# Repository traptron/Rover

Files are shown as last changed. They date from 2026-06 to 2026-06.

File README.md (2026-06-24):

# Rover - Инструкция по аппаратному обеспечению и тестированию

Данный документ содержит полное описание архитектуры прошивки, распиновку для подключения аппаратной части (драйверов DRV8871 и энкодеров) к микроконтроллеру STM32F429ZI, а также инструкцию по диагностике и тестированию системы.

---

## 1. Аппаратное подключение к STM32 
В помощь https://os.mbed.com/platforms/ST-Nucleo-F429ZI/

### 1.1. Драйверы двигателей DRV8871
Каждый из 6 моторов управляется отдельным драйвером DRV8871. Управление осуществляется по двум линиям: `IN1` (ШИМ-сигнал мощности) и `IN2` (логический уровень направления).

**Особенности работы с DRV8871:**
В прошивке реализована специальная логика для исключения состояния аппаратного торможения (Brake), когда на обоих входах драйвера логическая `1`:
- **Движение вперед:** `IN2` (DIR) = 0, `IN1` (PWM) = Прямая скважность от ПИД-регулятора.
- **Движение назад:** `IN2` (DIR) = 1, `IN1` (PWM) = Инвертированная скважность (`MAX_PWM - |мощность|`).

| Мотор | Сторона | Пин IN2 (DIR) | Пин IN1 (PWM) | Таймер и Канал ШИМ |
|---|---|---|---|---|
| **0** | Левая | **PF0** | **PE5** | TIM9_CH1 |
| **1** | Левая | **PF1** | **PF6** | TIM10_CH1 |
| **2** | Левая | **PF2** | **PF7** | TIM11_CH1 |
| **3** | Правая  | **PF3** | **PB15** | TIM12_CH2 |
| **4** | Правая  | **PF4** | **PF8** | TIM13_CH1 |
| **5** | Правая  | **PF5** | **PF9** | TIM14_CH1 |

*💡 Примечание:* Если при команде "вперед" какой-то мотор крутится назад, вы можете либо физически поменять местами силовые провода мотора (рекомендуется), либо программно инвертировать логику для конкретного мотора в `Core/Src/motor.c`.

### 1.2. Аппаратные энкодеры
Для определения текущей скорости и пробега используются квадратурные энкодеры. Выходы фаз A и B подключены напрямую к входам аппаратных таймеров STM32, работающих в режиме аппаратного энкодера.

| Энкодер | Пин Фазы A (CH1) | Пин Фазы B (CH2) | Используемый Таймер |
|---|---|---|---|
| **0** | **PE9** | **PE11** | TIM1 |
| **1** | **PA5** | **PB3** | TIM2 (32-bit) |
| **2** | **PA6** | **PB5** | TIM3 |
| **3** | **PD12** | **PD13** | TIM4 |
| **4** | **PA0** | **PA1** | TIM5 (32-bit) |
| **5** | **PC6** | **PC7** | TIM8 |

### 1.3. Связь с управляющим компьютером (UART4)
Обмен телеметрией и целевыми командами (Target Speeds) с хостом (например, Orange Pi или Raspberry Pi) происходит по интерфейсу UART с использованием DMA для минимизации нагрузки на процессор. Скорость обмена — **115200 бод**, частота отправки пакетов — 50 Гц (20 мс).

- **PC10 (TX)** -> RX-пин Orange Pi.
- **PC11 (RX)** -> TX-пин Orange Pi.
- **GND** -> **ОБЯЗАТЕЛЬНО** соедините земли (GND) STM32 и Orange Pi вместе.

В системе реализован **Failsafe**: если валидные пакеты от управляющего ПК не приходят более 500 мс, все моторы принудительно останавливаются, чтобы избежать аварии.

---

## 2. Сборка и Прошивка 

Обновление программного обеспечения микроконтроллера требует перекомпиляции и загрузки новой прошивки:

1. **Сборка проекта:** Скомпилируйте проект в вашей IDE (или через терминал `cmake --build build`). Дождитесь сообщения об успешном завершении сборки.
2. **Прошивка STM32:** Загрузите полученный файл `Rover.elf` / `Rover.bin` через ST-Link с помощью STM32CubeProgrammer или встроенных средств вашей IDE.
3. **Перезагрузка:** Нажмите кнопку **Reset** на микроконтроллере для запуска нового кода.

*(Если не прошить контроллер, плата продолжит выполнять старый код).*

---

## 3. Управляющий ПК: Зависимости и Установка

Для запуска скрипта тестирования `test_serial.py` и работы ROS 2 пакета `uart_bridge_pkg` на управляющем компьютере (например, Orange Pi 3b) необходимо установить следующие зависимости.

### 3.1. Список зависимостей
* **Системные (ROS 2 Humble):** `rclpy`, `geometry_msgs`, `nav_msgs`, `std_msgs` (поставляются вместе со средой ROS 2).
* **Python-библиотеки:**
  * `pyserial` — обмен данными с STM32 через UART.
  * `Flask` — веб-сервер панели мониторинга.
  * `Flask-SocketIO` — WebSocket-сервер для обновления графиков в реальном времени.

### 3.2. Команды для установки

**Способ 1: Через пакетный менеджер APT (Рекомендуется для Orange Pi / Ubuntu)**
Устанавливает зависимости на системном уровне без конфликтов с PEP 668:
```bash
sudo apt update
sudo apt install python3-serial python3-flask python3-flask-socketio
```

**Способ 2: Через pip**
Если вы используете виртуальное окружение или устанавливаете библиотеки напрямую:
```bash
pip3 install pyserial Flask Flask-SocketIO
```
*Примечание: на современных версиях ОС при попытке глобальной установки pip выдаст ошибку "externally-managed-environment". В этом случае используйте флаг `--break-system-packages`:*
```bash
pip3 install pyserial Flask Flask-SocketIO --break-system-packages
```

### 3.3. Настройка прав доступа к UART-порту
Для доступа к последовательным интерфейсам без прав `sudo` добавьте пользователя в группу `dialout`:
```bash
sudo usermod -a -G dialout $USER
```
*После выполнения команды перезайдите в систему или перезапустите ПК.*

---

## 4. Тестирование и диагностика (test_serial.py)

Для базовой проверки электроники без необходимости разворачивать ROS2 стек, используйте утилиту `Scripts/test_serial.py`.

### 4.1. Запуск
Подключите управляющий компьютер к STM32 по UART и выполните команду:
```bash
python3 Scripts/test_serial.py
```
*(Убедитесь, что переменная `SERIAL_PORT` в скрипте указывает на правильный порт, например `/dev/ttyS7` или `/dev/ttyUSB0`).*

### 4.2. Порядок проверки системы

**Шаг 1. Проверка чтения энкодеров (без моторов)**
1. Запустите скрипт, не подавая команду на скорость (`linear_x = 0`).
2. Вручную вращайте колеса ровера вперед по одному.
3. В консоли должны обновляться данные энкодеров: `[RX] Энкодеры: (15, 0, 0, 0, 0, 0)`.
4. При вращении вперед значения должны **расти** (в плюс), при вращении назад — **уменьшаться** (в минус).
5. *🔧 Исправление:* Если при вращении вперед значение уходит в минус, **поменяйте местами провода фаз A и B** на колодке контроллера для данного мотора.

**Шаг 2. Проверка моторов и ПИД-регулятора**
1. Введите в терминал скрипта тестовую скорость: `linear_x: 0.3` (Enter).
2. Моторы начнут вращаться. ПИД-регулятор внутри STM32 автоматически подберет необходимую мощность ШИМ на основании обратной связи от энкодеров.
3. Попробуйте придержать вращающееся колесо рукой — вы почувствуете увеличение крутящего момента (работа интегральной компоненты ПИД).
4. Введите `linear_x: 0.0` для остановки моторов.

---

## 5. Частые проблемы и их решение

* **Энкодеры всегда показывают нули:** 
  Убедитесь в наличии питания (3.3V/5V) на энкодерах. Проверьте правильность подключения сигнальных пинов к `TIMx_CH1` и `TIMx_CH2`.

* **Мотор уходит "вразнос" (мгновенно раскручивается до 100% при малой заданной скорости):**
  Возникла положительная обратная связь ПИД-регулятора. Мотор физически крутится вперед, но энкодер инвертирован и считает в минус. ПИД пытается "догнать" целевую скорость, увеличивая мощность ШИМ до максимума.
  **Решение:** Поменяйте местами фазы A и B энкодера ИЛИ поменяйте местами силовые провода мотора (в зависимости от того, куда физически едет колесо).

* **Ошибка CRC (`Ошибка CRC: calc=XX, recv=YY`) в скрипте:**
  Нарушена целостность данных по UART. Убедитесь в надежности контактов, наличии общего GND и, при необходимости, используйте экранированные провода или снизьте скорость (Baud Rate).

* **Пакеты идут без ошибок CRC, но моторы стоят:**
  Проверьте силовое питание (12V/24V) на драйверах DRV8871. Убедитесь, что силовая земля (GND) батареи объединена с сигнальной GND STM32. С помощью осциллографа или мультиметра проверьте уровни на пинах `IN2` (DIR, PF0-PF5) и наличие генерации на пинах `IN1` (PWM).

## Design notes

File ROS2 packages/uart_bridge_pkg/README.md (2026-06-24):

# Uart Bridge Package (`uart_bridge_pkg`)

ROS 2 пакет для мостового соединения (UART Bridge) между одноплатным компьютером Orange Pi 3b и микроконтроллером STM32. 

Нода `uart_bridge_node` транслирует команды управления движением (`/cmd_vel`) в бинарные пакеты для STM32, а также читает данные 6 энкодеров по UART, рассчитывает одометрию с помощью прямой кинематики (skid-steering) и публикует ее в топик `/odom`. Кроме того, нода поддерживает динамическое изменение параметров ПИД-регуляторов моторов "на лету" (например, через `rqt`).

## Особенности
* **Прямая трансляция управления:** Конвертирует `geometry_msgs/msg/Twist` в компактные бинарные UART-пакеты с расчетом контрольной суммы (CRC-8).
* **Расчет одометрии (Skid-Steering):** Опрашивает энкодеры в отдельном потоке, переводит тики в метры и вычисляет координаты X, Y, Theta на основе ширины колеи (290 мм) и геометрии 6 колес.
* **Настройка ПИД "на лету":** Обработчик параметров ROS 2 позволяет отправлять пакеты настройки на микроконтроллер без перезапуска ноды.
* **Веб-дашборд (`web_dashboard_node`):** Встроенный Flask + SocketIO сервер для отображения графиков энкодеров в реальном времени и настройки ПИД-коэффициентов через веб-интерфейс в локальной сети.

## Топики

### Подписки (Subscribers)
* **`/cmd_vel`** (`geometry_msgs/msg/Twist`): Целевая скорость робота. 
  * Используются поля `linear.x` (линейная скорость) и `angular.z` (угловая скорость).

### Публикации (Publishers)
* **`/odom`** (`nav_msgs/msg/Odometry`): Локальная одометрия робота (X, Y, Theta). 
  * Публикуется с фреймами `odom` -> `base_link` (публикация TF-трансформации отключена).
* **`/encoders_raw`** (`std_msgs/msg/Int32MultiArray`): Сырые значения энкодеров (разница тиков с прошлого пакета) для всех 6 колес. Используется для отладки.

## Параметры ROS 2 (Parameters)

| Имя параметра | Тип | По умолчанию | Описание |
|---|---|---|---|
| `serial_port` | string | `/dev/ttyS7` | Имя устройства UART-порта на Orange Pi 3b |
| `baudrate` | integer | `115200` | Скорость передачи данных UART |
| `motor_id` | integer | `0` | ID мотора (0-5) для отправки новых ПИД-коэффициентов |
| `kp` | double | `1.0` | Пропорциональный коэффициент (P) для `motor_id` |
| `ki` | double | `0.0` | Интегральный коэффициент (I) для `motor_id` |
| `kd` | double | `0.0` | Дифференциальный коэффициент (D) для `motor_id` |

*Примечание: При изменении параметров `kp`, `ki`, `kd` или `motor_id` (например, через `rqt` или `ros2 param set`), нода автоматически формирует пакет и отправляет его по UART в STM32.*

## Зависимости

Для работы пакета требуются следующие зависимости:

### Системные зависимости (ROS 2 Humble)
Обычно поставляются вместе с базовой установкой ROS 2:
* `rclpy`
* `geometry_msgs`
* `nav_msgs`
* `std_msgs`

### Python-зависимости
Для связи по UART и работы веб-интерфейса панели управления:
* `pyserial` — для работы с последовательным портом UART.
* `Flask` — веб-фреймворк для бэкенда панели.
* `Flask-SocketIO` — WebSocket-сервер для передачи показаний в реальном времени.

### Команды для установки зависимостей

**Вариант 1: Установка через пакетный менеджер APT (Рекомендуется на Orange Pi / Ubuntu)**
Этот способ предпочтителен, так как он устанавливает пакеты системно и не вызывает конфликтов с PEP 668:
```bash
sudo apt update
sudo apt install python3-serial python3-flask python3-flask-socketio
```

**Вариант 2: Установка через pip**
Если вы используете виртуальное окружение или системные пакеты недоступны:
```bash
pip3 install pyserial Flask Flask-SocketIO
```
*Примечание: на современных ОС (например, Debian 12 / Ubuntu 24.04 / Armbian) при попытке глобальной установки pip выдаст ошибку "externally-managed-environment". В таком случае можно использовать флаг `--break-system-packages`:*
```bash
pip3 install pyserial Flask Flask-SocketIO --break-system-packages
```

---

## Установка и сборка

1. Перенесите папку `uart_bridge_pkg` в директорию `src` вашего ROS 2 workspace на Orange Pi 3b.
   ```bash
   cd ~/ros2_ws/src
   # Убедитесь, что папка uart_bridge_pkg находится здесь
   ```

2. Соберите пакет с помощью `colcon`:
   ```bash
   cd ~/ros2_ws
   colcon build --packages-select uart_bridge_pkg
   ```

3. Подгрузите окружение workspace:
   ```bash
   source install/setup.bash
   ```

## Запуск

### Базовый запуск
Теперь вы можете запустить обе ноды (UART мост и веб-дашборд) одной командой:
```bash
ros2 launch uart_bridge_pkg rover_bridge.launch.py
```

### Запуск отдельных компонентов
Если вам нужно запустить только UART мост:
```bash
ros2 run uart_bridge_pkg uart_bridge_node --ros-args -p serial_port:=/dev/ttyS0 -p baudrate:=115200
```
Для запуска только веб-дашборда:
```bash
ros2 run uart_bridge_pkg web_dashboard_node
```

После запуска интерфейса (через `launch` или отдельно), откройте браузер на любом устройстве в вашей локальной сети по адресу:
`http://<IP_адрес_Orange_Pi>:5000`

## Права доступа к UART
Убедитесь, что ваш пользователь на Orange Pi находится в группе `dialout` (или `tty`), чтобы иметь права на чтение/запись в `/dev/ttyS7` без `sudo`:
```bash
sudo usermod -a -G dialout $USER
# После этого нужно перезайти в систему или выполнить su - $USER
```

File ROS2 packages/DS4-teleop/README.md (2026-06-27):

# Телеоперация 6-колёсного ровера через DualShock 4

Узел ROS2 Humble для управления 6-колёсным ровером с помощью джойстика DualShock 4, подключённого по Bluetooth к Orange Pi 3B.

## Архитектура

```
DualShock 4 (Bluetooth)
    ↓
/dev/input/event5
    ↓
joy_node → /joy (sensor_msgs/Joy)
    ↓
teleop_node → /cmd_vel (geometry_msgs/Twist)
    ↓
STM32 Motor Controller (UART)
```

## Управление

| Действие | Кнопка | Эффект |
|---|---|---|
| Движение вперёд | R2 (триггер) | linear.x → [0, +max] |
| Движение назад | L2 (триггер) | linear.x → [-max, 0] |
| Поворот | Left Stick X | angular.z → [-max, +max] |

**Нормализация триггеров:** Триггеры из диапазона `[1.0, -1.0]` переводятся в `[0, 1]` по формуле:
```
value = (1.0 - axis) / 2.0
```

## Быстрый старт

### 1. Сборка пакета

```bash
cd ~/rover_ws
colcon build --packages-select teleop_DS4
source install/setup.bash
```

### 2. Запуск системы

```bash
ros2 launch teleop_DS4 teleop.launch.py joy_device:=/dev/input/event5
```

### 3. Отладка (с выводом логов)

```bash
ros2 launch teleop_DS4 teleop.launch.py \
  joy_device:=/dev/input/event5 \
  debug:=true
```

## Мониторинг

### Просмотр команд скорости

```bash
ros2 topic echo /cmd_vel
```

### Просмотр входных данных джойстика

```bash
ros2 topic echo /joy
```

### Список параметров

```bash
ros2 param list /teleop_ds4_node
```

## Параметры

| Параметр | Тип | Значение по умолчанию | Описание |
|---|-----|---|---|
| `max_linear_speed` | float | 1.0 | Максимальная линейная скорость (м/с) |
| `max_angular_speed` | float | 1.0 | Максимальная угловая скорость (рад/с) |
| `deadzone` | float | 0.05 | Мёртвая зона для аналоговых входов [0, 1] |
| `accel_limit` | float | 0.5 | Ограничение ускорения (ед/с²) |
| `watchdog_timeout` | float | 0.2 | Таймаут отказа безопасности (сек) |
| `debug` | bool | false | Включить отладочные логи |

### Изменение параметров во время работы

```bash
# Установить максимальную скорость
ros2 param set /teleop_ds4_node max_linear_speed 2.0

# Включить отладку
ros2 param set /teleop_ds4_node debug true
```

## Безопасность

1. **Watchdog Timer** — если сообщение от джойстика не получено в течение 200 мс, публикуется нулевая скорость
2. **Deadzone** — входы ниже порога 0.05 игнорируются (исключает дрейф)
3. **Rate Limiting** — ограничение ускорения предотвращает резкие прыжки скорости
4. **Clamping** — все выходы ограничены диапазоном `[-max, +max]`

## Техническое описание

### Вычисление скорости

```python
# Нормализация триггеров
L2_norm = (1.0 - L2_raw) / 2.0   # [1, -1] → [0, 1]
R2_norm = (1.0 - R2_raw) / 2.0   # [1, -1] → [0, 1]

# Вычисление желаемых скоростей
linear = (R2_norm - L2_norm) * max_linear_speed
angular = left_stick_x * max_angular_speed

# Применение мёртвой зоны, ограничение и сглаживание
# ...

# Публикация
twist.linear.x = linear
twist.angular.z = angular
```

### Цикл управления

- **Основной цикл** — 50 Гц (публикация `/cmd_vel`)
- **Watchdog** — 100 Гц (проверка timeout)
- **Отладочные логи** — 5 Гц (throttled)

## Устранение неполадок

### Джойстик не распознаётся

```bash
# Проверить, что устройство доступно
ls -la /dev/input/event*

# Проверить права доступа
sudo usermod -a -G input $USER
```

### Нет команд на `/cmd_vel`

```bash
# Проверить, что joy_node работает
ros2 topic echo /joy

# Если нет данных, проверить джойстик
ros2 node list | grep joy
```

### Предупреждения Watchdog

```
[WARN] Watchdog timeout: no joy message for 0.200s
```
Джойстик потерял связь. Проверьте Bluetooth соединение.

## Индексы осей DualShock 4 (стандартная нумерация)

| Ось | Индекс | Диапазон | Описание |
|-----|---|---|---|
| LX | 0 | [-1, 1] | Left stick X |
| LY | 1 | [-1, 1] | Left stick Y |
| RX | 2 | [-1, 1] | Right stick X |
| RY | 3 | [-1, 1] | Right stick Y |
| L2 | 4 | [1, -1] | L2 триггер |
| R2 | 5 | [1, -1] | R2 триггер |

## Зависимости

- ROS2 Humble
- rclpy
- sensor_msgs
- geometry_msgs
- joy (пакет для чтения джойстика)

## Сборка и установка

```bash
# Вспомогательные зависимости
rosdep install --from-paths src --ignore-src -r -y

# Сборка
colcon build --packages-select teleop_DS4

# Источник
source install/setup.bash
```

## Тестирование

```bash
# Запустить с тестовыми параметрами
ros2 launch teleop_DS4 teleop.launch.py \
  max_linear_speed:=0.5 \
  max_angular_speed:=0.5 \
  debug:=true
```

## Лицензия

Apache-2.0

## Автор

traptron

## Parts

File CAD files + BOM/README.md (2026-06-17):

# BOM для rocker-bogie ровера

Этот список содержит CAD детали и электронику/механику для проекта rocker-bogie ровера. Количества указаны на один ровер.

## CAD детали (3D печать или мехобработка)

- Колесо, обод, шина, крепление: 6 шт
- Rocker, bogie: 2 шт
- Корпус: по 1 шт на каждую деталь
- Дифференциальная балка: 1 шт

## Электроника и механика

- Плата питания: 1 шт (описание ниже)

| Наименование | Кол-во | Ссылка |
| --- | --- | --- |
| Orange Pi 3B (рекомендуется 8GB RAM) | 1 | - |
| NUCLEO STM32F429ZI | 1 | - |
| JGA25-370 12V 130rpm с энкодером | 6 | https://aliexpress.ru/item/32855724293.html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 |
| XL4015 DC-DC step-down | 1-2 | - |
| Аккумулятор 18650 | 8 | - |
| Держатель 18650 на 4 слота | 2 | https://aliexpress.ru/item/1005003595795784.html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 |
| BMS 4S 16.8V 40A (рекомендуется 100A) | 1 | https://aliexpress.ru/item/4000274128382.html?spm=a2g2w.orderlist.0.0.48514aa6wYXTMo&sku_id=12000037978159621 |
| Зарядное устройство 16.8V 2A | 1 | https://aliexpress.ru/item/1005006648286527.html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 |
| DRV8871 H-bridge | 6 | https://aliexpress.ru/item/1005009205001091.html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 |
| Переключатель KCD4 | 1 | https://aliexpress.ru/item/10000335722912.html?spm=a2g2w.orderlist.0.0.48514aa6wYXTMo&sku_id=20000000175766813 |
| Шарнирные наконечники SI8 | 2 | https://aliexpress.ru/item/1005005898128558.html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 |
| Шарнирные наконечники SA8 | 2 | https://aliexpress.ru/item/1005005898128558.html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 |
| Подшипник 608zz | 10 | https://aliexpress.ru/item/1005006648286527.html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 |
| DC-099 разъем питания 5.5x2.1 | 1 | https://aliexpress.ru/item/1005008928703998.html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 |

## Плата питания

Плата изготавливается методом ЛУТ (https://youtu.be/NJTeIALlztI?si=GeW6YX7Ok-37P5MD). Для своей платы я использовал тонкий (0.5 мм) стеклотекстолит с двухсторонним фольгированием, лучше брать текстолит потолще с слоем меди 70 мкм. Если слой меди около 30 мкм и менее, рекомендуется усилить дорожки медным проводом. Плата травилась в водном растворе персульфата аммония при температуре 40-50 градусов, при температуре меньше 40 градусов реакция практически не идёт. На плате предусмотрены площадки под разъёмы XT30 для подключаемой нагрузки (драйверы, преобразователи напряжения и т.д.). Для подключения разъёмов следует припаять провода от дорожек VCC и GND (обратная сторона платы) соответсвенно к + и - выходов XT30.

## Критерии подбора компонентов

- BMS: непрерывный ток должен быть выше суммарного пикового тока всех моторов с запасом.
- Драйверы моторов: поддержка напряжения 12V и достаточный ток на канал с учетом пусковых токов.
- Энкодеры: желательно 2-канальные (квадратурные) для контроля направления и скорости.
- Аккумуляторы: одинаковая емкость и внутренняя сопротивляемость для ровной работы 4S сборки.
- DC-DC: обеспечить запас по мощности для одновременной нагрузки контроллеров и логики.

## Заметки по проводке

- Силовая проводка: AWG10 или AWG12.
- Балансные линии BMS: тонкие провода малого сечения.
- Логика: DuPont провода.

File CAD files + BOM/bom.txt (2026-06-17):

Wheel, Rim, Tire, Mount - 6 pieces
Rockie, Bogie - 2 pieces
Body - 1 piece for each part
Differential bar - 1 piece

Orange Pi 3B (8GB RAM recommended) - 1 piece
NUCLEO STM32F429ZI - 1 piece
JGA25-370 12V 130rpm with encoder - 6 pieces https://aliexpress.ru/item/32855724293.html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
XL4015 DC-DC step-down - 1-2 pieces 
18650 Battery - 8 pieces
18650 Battery holder 4x slot - 2 pieces https://aliexpress.ru/item/1005003595795784.html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
BMS 4S 16.8V 40A (100A recommended) - 1 piece https://aliexpress.ru/item/4000274128382.html?spm=a2g2w.orderlist.0.0.48514aa6wYXTMo&sku_id=12000037978159621
Charger 16.8V 2A - 1 piece https://aliexpress.ru/item/1005006648286527.html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
DRV8871 H-bridge - 6 pieces https://aliexpress.ru/item/1005009205001091.html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
KCD4 rocker switch - 1 piece https://aliexpress.ru/item/10000335722912.html?spm=a2g2w.orderlist.0.0.48514aa6wYXTMo&sku_id=20000000175766813
Rod Ends SI8 - 2 pieces https://aliexpress.ru/item/1005005898128558.html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
Rod Ends SA8 - 2 pieces https://aliexpress.ru/item/1005005898128558.html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
Bearing 608zz - 10 pieces https://aliexpress.ru/item/1005006648286527.html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
DC-099 Power Jack Socket 5.5x2.1 - 1 piece https://aliexpress.ru/item/1005008928703998.html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

For power wiring, AWG10 or AWG12 wires are required.
For BMS use small cross-section wires.
For logic use DuPont wires.

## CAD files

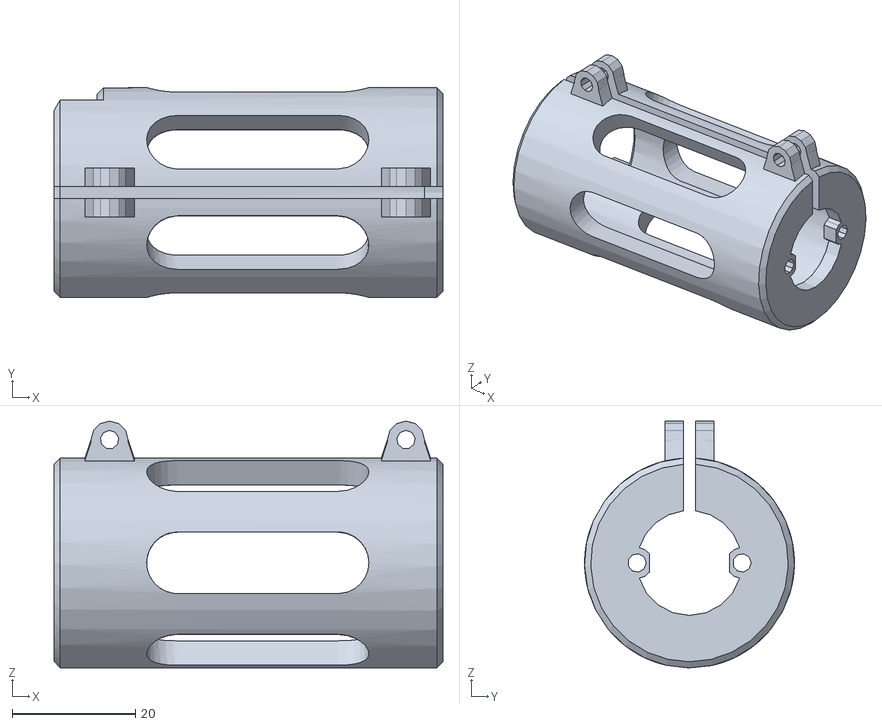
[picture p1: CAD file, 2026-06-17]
CAD files + BOM/Motor mount.stl
63.0 x 34.0 x 40.0

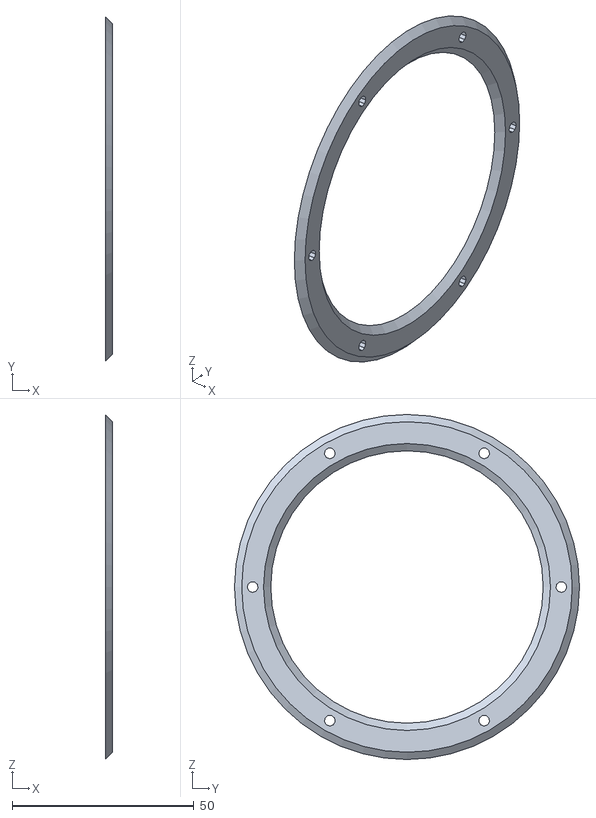
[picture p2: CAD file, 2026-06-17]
CAD files + BOM/Rim.stl
2.00 x 95.0 x 95.0

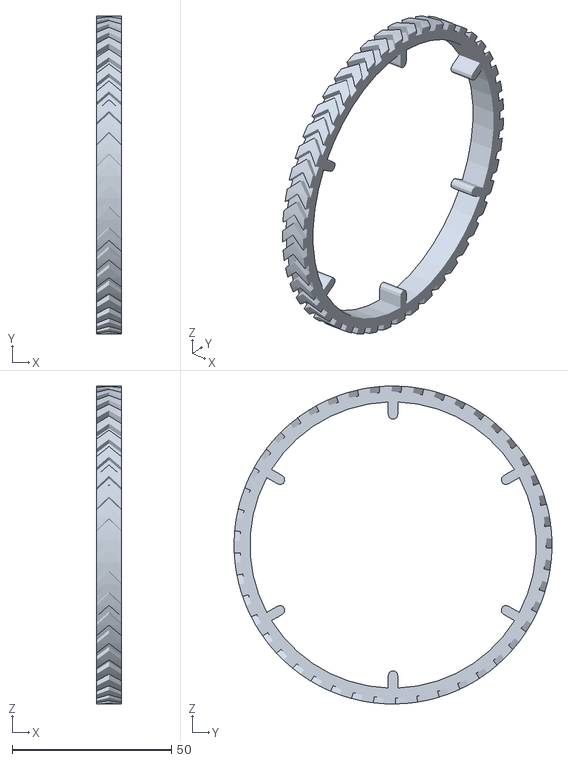
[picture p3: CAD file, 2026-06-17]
CAD files + BOM/Tire.stl
8.00 x 100.0 x 100.0

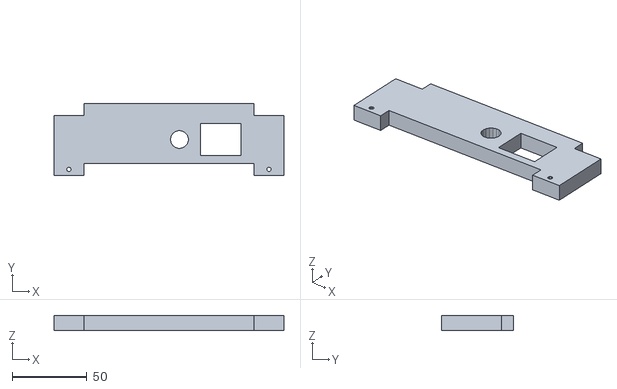
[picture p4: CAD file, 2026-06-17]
CAD files + BOM/Body (back).stl
154.0 x 48.0 x 10.0

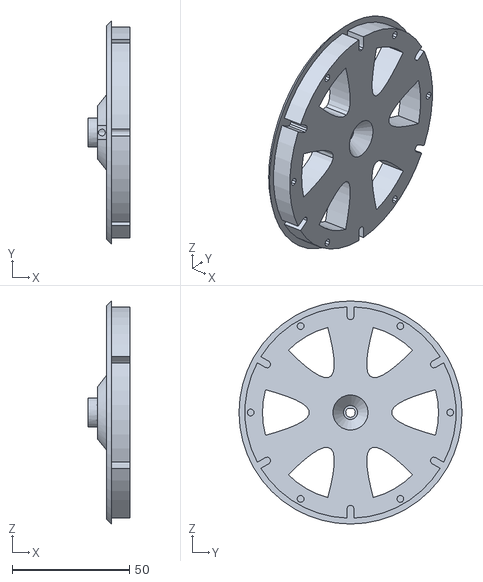
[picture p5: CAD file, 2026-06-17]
CAD files + BOM/Wheel.stl
18.0 x 95.0 x 95.0

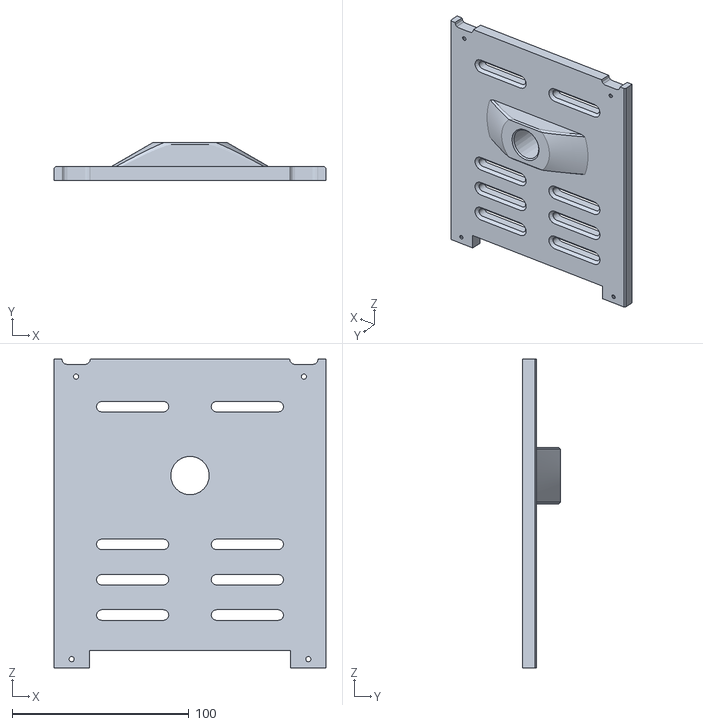
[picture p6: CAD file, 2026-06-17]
CAD files + BOM/Body (top) - 2.stl
154.0 x 21.5 x 175.0

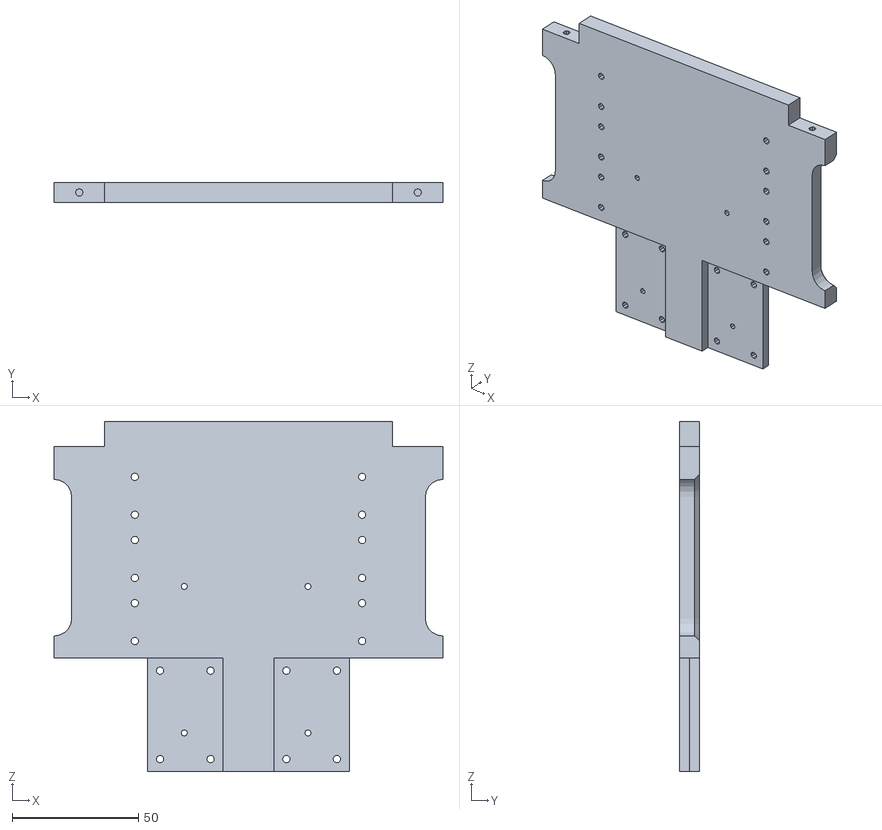
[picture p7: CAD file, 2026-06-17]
CAD files + BOM/Body (bottom) - 2.stl
154.0 x 8.00 x 138.7

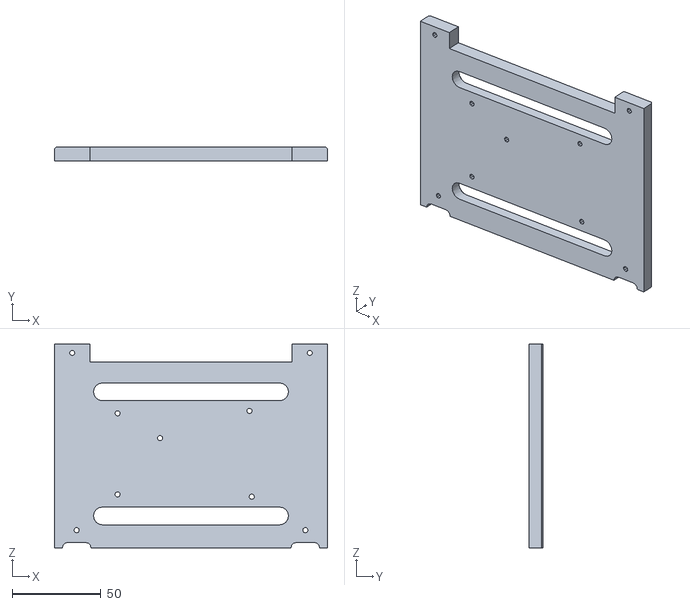
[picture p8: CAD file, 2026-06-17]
CAD files + BOM/Body (top) - 1.stl
154.0 x 8.00 x 115.0

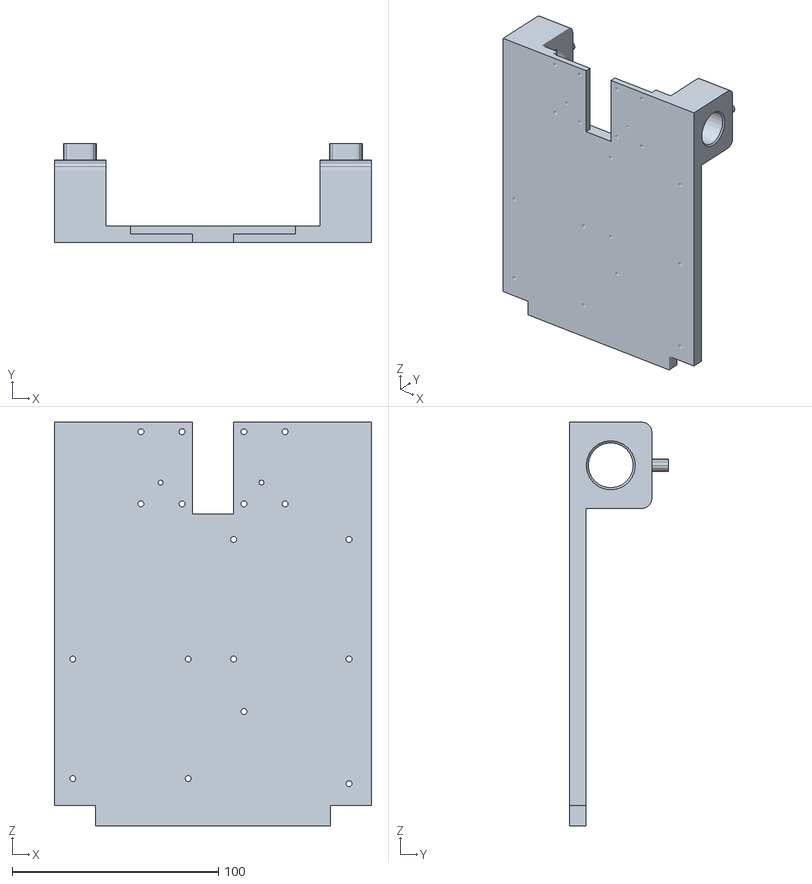
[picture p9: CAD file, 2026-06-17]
CAD files + BOM/Body (bottom) - 1.stl
154.0 x 48.0 x 196.0

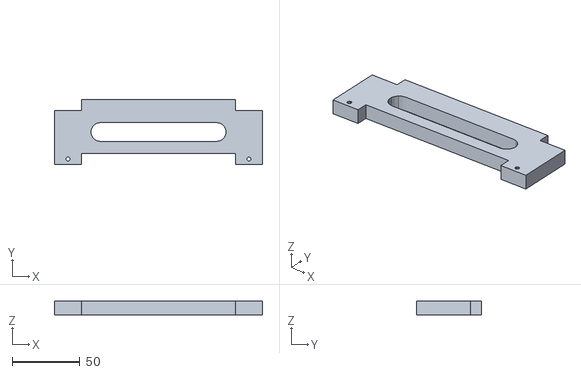
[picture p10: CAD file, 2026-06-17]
CAD files + BOM/Body (front).stl
154.0 x 48.0 x 10.0

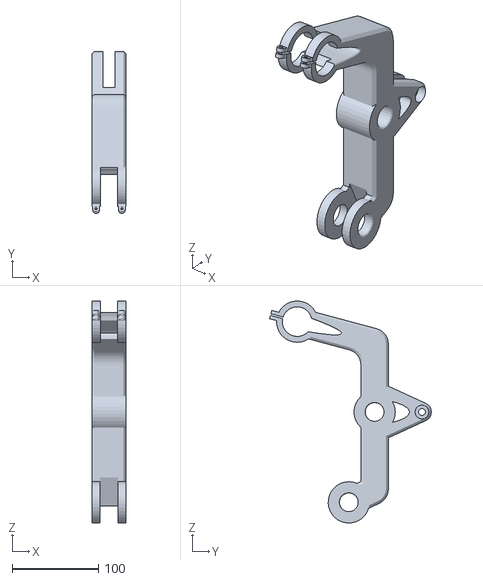
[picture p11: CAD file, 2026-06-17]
CAD files + BOM/Rockie.stl
40.0 x 188.1 x 258.0

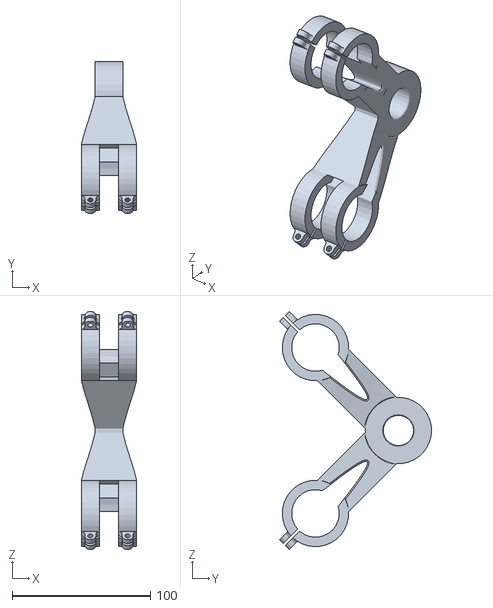
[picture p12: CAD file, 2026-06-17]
CAD files + BOM/Bogie.stl
40.0 x 110.1 x 172.2

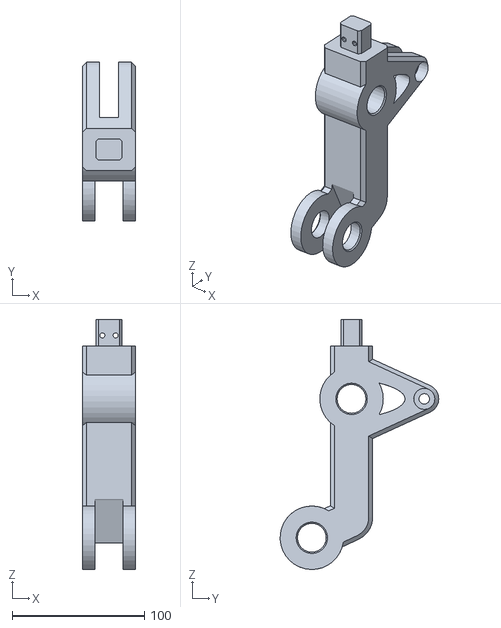
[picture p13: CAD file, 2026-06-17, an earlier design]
CAD files + BOM/Rockie (1).stl
40.0 x 119.9 x 189.0

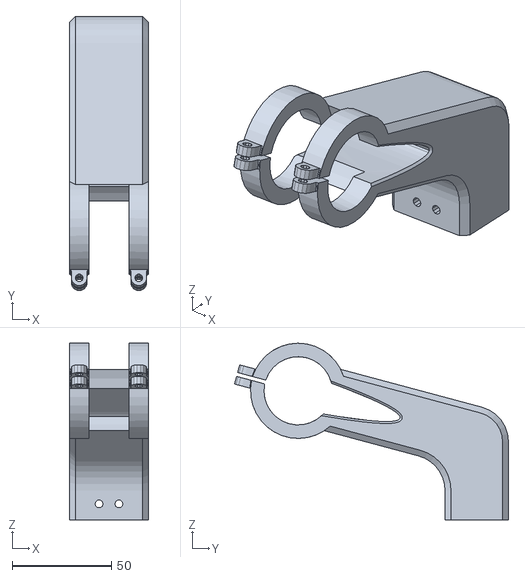
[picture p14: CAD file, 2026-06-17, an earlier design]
CAD files + BOM/Rockie (2).stl
40.0 x 138.1 x 89.0

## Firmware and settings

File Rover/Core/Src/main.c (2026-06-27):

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
/* Includes ------------------------------------------------------------------*/
#include "main.h"

/* USER CODE BEGIN Includes */
#include "protocol.h"
#include "motor.h"
#include "encoder.h"
/* USER CODE END Includes */

TIM_HandleTypeDef htim1;
TIM_HandleTypeDef htim2;
TIM_HandleTypeDef htim3;
TIM_HandleTypeDef htim4;
TIM_HandleTypeDef htim5;
TIM_HandleTypeDef htim8;
TIM_HandleTypeDef htim9;
TIM_HandleTypeDef htim10;
TIM_HandleTypeDef htim11;
TIM_HandleTypeDef htim12;
TIM_HandleTypeDef htim13;
TIM_HandleTypeDef htim14;

UART_HandleTypeDef huart4;
DMA_HandleTypeDef hdma_uart4_rx;
DMA_HandleTypeDef hdma_uart4_tx;

/* USER CODE BEGIN PV */
uint8_t rx_byte;
/* USER CODE END PV */

void SystemClock_Config(void);
static void MX_GPIO_Init(void);
static void MX_DMA_Init(void);
static void MX_UART4_Init(void);
static void MX_TIM1_Init(void);
static void MX_TIM2_Init(void);
static void MX_TIM3_Init(void);
static void MX_TIM4_Init(void);
static void MX_TIM5_Init(void);
static void MX_TIM8_Init(void);
static void MX_TIM9_Init(void);
static void MX_TIM10_Init(void);
static void MX_TIM11_Init(void);
static void MX_TIM12_Init(void);
static void MX_TIM13_Init(void);
static void MX_TIM14_Init(void);
/**
  * @brief  The application entry point.
  * @retval int
  */
int main(void)
{

  /* MCU Configuration--------------------------------------------------------*/

  /* Reset of all peripherals, Initializes the Flash interface and the Systick. */
  HAL_Init();

  /* Configure the system clock */
  SystemClock_Config();

  /* Initialize all configured peripherals */
  MX_GPIO_Init();
  MX_DMA_Init();
  MX_UART4_Init();
  MX_TIM1_Init();
  MX_TIM2_Init();
  MX_TIM3_Init();
  MX_TIM4_Init();
  MX_TIM5_Init();
  MX_TIM8_Init();
  MX_TIM9_Init();
  MX_TIM10_Init();
  MX_TIM11_Init();
  MX_TIM12_Init();
  MX_TIM13_Init();
  MX_TIM14_Init();
  /* USER CODE BEGIN 2 */
  HAL_UART_Receive_IT(&huart4, &rx_byte, 1);
  
  Master_PID_Init(&left_board_pid,  2.0f, 0.5f, 0.01f, 0.0f, 0.0f, (float)MAX_PWM);
  Master_PID_Init(&right_board_pid, 2.0f, 0.5f, 0.01f, 0.0f, 0.0f, (float)MAX_PWM);
  for (int i = 0; i < 6; i++) {
      Slave_Init(&wheel_slaves[i], 0.5f);
  }
  
  HAL_TIM_Encoder_Start(&htim1, TIM_CHANNEL_ALL);
  HAL_TIM_Encoder_Start(&htim2, TIM_CHANNEL_ALL);
  HAL_TIM_Encoder_Start(&htim3, TIM_CHANNEL_ALL);
  HAL_TIM_Encoder_Start(&htim4, TIM_CHANNEL_ALL);
  HAL_TIM_Encoder_Start(&htim5, TIM_CHANNEL_ALL);
  HAL_TIM_Encoder_Start(&htim8, TIM_CHANNEL_ALL);
  
  HAL_TIM_PWM_Start(&htim9, TIM_CHANNEL_1);
  HAL_TIM_PWM_Start(&htim10, TIM_CHANNEL_1);
  HAL_TIM_PWM_Start(&htim11, TIM_CHANNEL_1);
  HAL_TIM_PWM_Start(&htim12, TIM_CHANNEL_2);
  HAL_TIM_PWM_Start(&htim13, TIM_CHANNEL_1);
  HAL_TIM_PWM_Start(&htim14, TIM_CHANNEL_1);
  
  uint32_t last_tx_tick = HAL_GetTick();
  TxPacket tx_packet;
  tx_packet.header = 0xBBBB;
  for (int i = 0; i < 6; i++) {
      tx_packet.encoders[i] = 0;
  }
  /* USER CODE END 2 */

  /* Infinite loop */
  /* USER CODE BEGIN WHILE */
  while (1)
  {
    /* USER CODE END WHILE */

    /* USER CODE BEGIN 3 */
    if (HAL_GetTick() - last_tx_tick >= 20) { // 50 Гц (20 мс)
        last_tx_tick += 20;
        
        // Failsafe проверка: если данных не было > 500 мс
        if (HAL_GetTick() - last_packet_time > 500) {
            target_left_speed = 0.0f;
            target_right_speed = 0.0f;
            left_board_pid.integral_sum = 0.0f;
            right_board_pid.integral_sum = 0.0f;
            HAL_GPIO_WritePin(LD1_GPIO_Port, LD1_Pin, GPIO_PIN_RESET); // Зеленый ВЫКЛ
            HAL_GPIO_WritePin(LD3_GPIO_Port, LD3_Pin, GPIO_PIN_SET);   // Красный ВКЛ
            
            // Мигаем синим светодиодом (LD2) раз в 250 мс
            if ((HAL_GetTick() / 250) % 2 == 0) {
                HAL_GPIO_WritePin(LD2_GPIO_Port, LD2_Pin, GPIO_PIN_SET);
            } else {
                HAL_GPIO_WritePin(LD2_GPIO_Port, LD2_Pin, GPIO_PIN_RESET);
            }
        } else {
            // При нормальной связи синий светодиод выключен
            HAL_GPIO_WritePin(LD2_GPIO_Port, LD2_Pin, GPIO_PIN_RESET);
        }
        
        read_encoders();
        
        // Накопление тиков для TX-пакета
        for (int i = 0; i < 6; i++) {
            tx_packet.encoders[i] += current_speeds[i];
        }
        
        // ПИД-управление (Master-Slave)
        float motor_outputs[6];
        update_rover_control(target_left_speed, target_right_speed, 0.02f, motor_outputs);
        
        apply_motor_power(motor_outputs);
        
        // Считаем CRC-8 от данных без байта CRC
        tx_packet.crc = calculate_crc8((uint8_t*)&tx_packet, sizeof(TxPacket) - 1);
        
        // Отправляем пакет по UART4 через DMA
        if (huart4.gState == HAL_UART_STATE_READY) {
            HAL_UART_Transmit_DMA(&huart4, (uint8_t*)&tx_packet, sizeof(TxPacket));
        }
    }
  }
  /* USER CODE END 3 */
}

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
/* USER CODE BEGIN 4 */
void HAL_UART_RxCpltCallback(UART_HandleTypeDef *huart) {
    if (huart->Instance == UART4) {
        // Отправляем байт в парсер
        parse_incoming_byte(rx_byte);
        
        // Снова запускаем прием следующего байта
        HAL_UART_Receive_IT(&huart4, &rx_byte, 1);
    }
}
/* USER CODE END 4 */
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


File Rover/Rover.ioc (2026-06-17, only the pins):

Mcu.UserName=STM32F429ZITx
PA0/WKUP.Signal=S_TIM5_CH1
PA1.Signal=S_TIM5_CH2
PA10.GPIO_Label=USB_ID
PA10.Signal=USB_OTG_FS_ID
PA11.GPIO_Label=USB_DM
PA11.Signal=USB_OTG_FS_DM
PA12.GPIO_Label=USB_DP
PA12.Signal=USB_OTG_FS_DP
PA13.GPIO_Label=TMS
PA13.Signal=SYS_JTMS-SWDIO
PA14.GPIO_Label=TCK
PA14.Signal=SYS_JTCK-SWCLK
PA2.GPIO_Label=RMII_MDIO [LAN8742A-CZ-TR_MDIO]
PA2.Signal=ETH_MDIO
PA5.Signal=S_TIM2_CH1_ETR
PA6.Signal=S_TIM3_CH1
PA7.GPIO_Label=RMII_CRS_DV [LAN8742A-CZ-TR_CRS_DV]
PA7.Signal=ETH_CRS_DV
PA8.GPIO_Label=USB_SOF [TP1]
PA8.Signal=USB_OTG_FS_SOF
PA9.GPIO_Label=USB_VBUS
PA9.Signal=USB_OTG_FS_VBUS
PB0.GPIO_Label=LD1 [Green]
PB0.Signal=GPIO_Output
PB13.GPIO_Label=RMII_TXD1 [LAN8742A-CZ-TR_TXD1]
PB13.Signal=ETH_TXD1
PB14.GPIO_Label=LD3 [Red]
PB14.Signal=GPIO_Output
PB15.Signal=S_TIM12_CH2
PB3.Signal=S_TIM2_CH2
PB5.Signal=S_TIM3_CH2
PB7.GPIO_Label=LD2 [Blue]
PB7.Signal=GPIO_Output
PC1.GPIO_Label=RMII_MDC [LAN8742A-CZ-TR_MDC]
PC1.Signal=ETH_MDC
PC10.Signal=UART4_TX
PC11.Signal=UART4_RX
PC13.GPIO_Label=USER_Btn [B1]
PC13.Signal=GPXTI13
PC14/OSC32_IN.Signal=RCC_OSC32_IN
PC15/OSC32_OUT.Signal=RCC_OSC32_OUT
PC4.GPIO_Label=RMII_RXD0 [LAN8742A-CZ-TR_RXD0]
PC4.Signal=ETH_RXD0
PC5.GPIO_Label=RMII_RXD1 [LAN8742A-CZ-TR_RXD1]
PC5.Signal=ETH_RXD1
PC6.Signal=S_TIM8_CH1
PC7.Signal=S_TIM8_CH2
PD12.Signal=S_TIM4_CH1
PD13.Signal=S_TIM4_CH2
PD8.GPIO_Label=STLK_RX [STM32F103CBT6_PA3]
PD8.Signal=USART3_TX
PD9.GPIO_Label=STLK_TX [STM32F103CBT6_PA2]
PD9.Signal=USART3_RX
PE11.Signal=S_TIM1_CH2
PE5.Signal=S_TIM9_CH1
PE9.Signal=S_TIM1_CH1
PF0.GPIO_Label=DIR_FL
PF0.Signal=GPIO_Output
PF1.GPIO_Label=DIR_ML
PF1.Signal=GPIO_Output
PF2.GPIO_Label=DIR_BL
PF2.Signal=GPIO_Output
PF3.GPIO_Label=DIR_FR
PF3.Signal=GPIO_Output
PF4.GPIO_Label=DIR_MR
PF4.Signal=GPIO_Output
PF5.GPIO_Label=DIR_BR
PF5.Signal=GPIO_Output
PF6.Signal=S_TIM10_CH1
PF7.Signal=S_TIM11_CH1
PF8.Signal=S_TIM13_CH1
PF9.Signal=S_TIM14_CH1
PG11.GPIO_Label=RMII_TX_EN [LAN8742A-CZ-TR_TXEN]
PG11.Signal=ETH_TX_EN
PG13.GPIO_Label=RMII_TXD0 [LAN8742A-CZ-TR_TXD0]
PG13.Signal=ETH_TXD0
PG6.Signal=GPIO_Output
PG7.GPIO_Label=USB_OverCurrent [STMPS2151STR_FAULT]
PG7.Signal=GPIO_Input
PH0/OSC_IN.GPIO_Label=MCO [STM32F103CBT6_PA8]
PH0/OSC_IN.Signal=RCC_OSC_IN
PH1/OSC_OUT.Signal=RCC_OSC_OUT

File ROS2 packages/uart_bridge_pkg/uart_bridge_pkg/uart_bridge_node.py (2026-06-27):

#!/usr/bin/env python3

import rclpy
from rclpy.node import Node
from rcl_interfaces.msg import SetParametersResult
from geometry_msgs.msg import Twist
from nav_msgs.msg import Odometry
from std_msgs.msg import Int32MultiArray
import serial
import threading
import struct
import math
import time

def calculate_crc8(data: bytes) -> int:
    crc = 0
    for byte in data:
        crc ^= byte
        for _ in range(8):
            if crc & 0x80:
                crc = ((crc << 1) ^ 0x07) & 0xFF
            else:
                crc = (crc << 1) & 0xFF
    return crc

def yaw_to_quaternion(yaw):
    return [0.0, 0.0, math.sin(yaw / 2.0), math.cos(yaw / 2.0)]

class UartBridgeNode(Node):
    def __init__(self):
        super().__init__('uart_bridge_node')
        
        # Объявление параметров
        self.declare_parameter('kp', 1.0)
        self.declare_parameter('ki', 0.0)
        self.declare_parameter('kd', 0.0)
        self.declare_parameter('kff', 0.0)
        self.declare_parameter('min_pwm', 0)
        self.declare_parameter('kp_sync', 0.0)
        self.declare_parameter('motor_id', 0)
        self.declare_parameter('serial_port', '/dev/ttyS7')
        self.declare_parameter('baudrate', 115200)

        # Переменные одометрии
        self.prev_encoders = None
        self.x = 0.0
        self.y = 0.0
        self.theta = 0.0
        
        # Константы
        self.TRACK_WIDTH = 0.29
        self.METERS_PER_TICK = (math.pi * 0.10) / (46.0 * 44.0)

        # Подключение к serial порту
        port = self.get_parameter('serial_port').value
        baudrate = self.get_parameter('baudrate').value
        try:
            self.ser = serial.Serial(port, baudrate, timeout=1.0)
            self.get_logger().info(f"Connected to {port} at {baudrate} baud.")
        except serial.SerialException as e:
            self.get_logger().error(f"Failed to connect to serial port: {e}")
            raise e

        # Обработчик изменения параметров
        self.add_on_set_parameters_callback(self.parameters_callback)

        # Паблишеры и сабскрайберы
        self.odom_pub = self.create_publisher(Odometry, '/odom', 10)
        self.encoders_pub = self.create_publisher(Int32MultiArray, '/encoders_raw', 10)
        self.cmd_vel_sub = self.create_subscription(Twist, '/cmd_vel', self.cmd_vel_cb, 10)

        # Запуск потока приема (RX)
        self.rx_thread = threading.Thread(target=self.rx_loop, daemon=True)
        self.rx_thread.start()

    def parameters_callback(self, params):
        updated = False
        kp = self.get_parameter('kp').value
        ki = self.get_parameter('ki').value
        kd = self.get_parameter('kd').value
        kff = self.get_parameter('kff').value
        min_pwm = self.get_parameter('min_pwm').value
        kp_sync = self.get_parameter('kp_sync').value
        motor_id = self.get_parameter('motor_id').value
        
        for param in params:
            if param.name == 'kp':
                kp = float(param.value)
                updated = True
            elif param.name == 'ki':
                ki = float(param.value)
                updated = True
            elif param.name == 'kd':
                kd = float(param.value)
                updated = True
            elif param.name == 'kff':
                kff = float(param.value)
                updated = True
            elif param.name == 'min_pwm':
                min_pwm = int(param.value)
                updated = True
            elif param.name == 'kp_sync':
                kp_sync = float(param.value)
                updated = True
            elif param.name == 'motor_id':
                motor_id = int(param.value)
                updated = True
        
        if updated:
            self.send_pid_tune(motor_id, kp, ki, kd, kff, min_pwm, kp_sync)
            self.get_logger().info(f"PID Tune Sent - Motor {motor_id}: Kp={kp}, Ki={ki}, Kd={kd}, Kff={kff}, MinPWM={min_pwm}, KpSync={kp_sync}")
        
        return SetParametersResult(successful=True)

    def send_pid_tune(self, motor_id, kp, ki, kd, kff, min_pwm, kp_sync):
        # Упаковка сообщения настройки ПИД (msg_id=2)
        # Заголовок (2), msg_id (1), motor_id (1), kp (4), ki (4), kd (4), kff (4), min_pwm (2), kp_sync_x100 (1)
        kp_sync_x100 = int(kp_sync * 100)
        if kp_sync_x100 < 0: kp_sync_x100 = 0
        if kp_sync_x100 > 255: kp_sync_x100 = 255
        
        payload = struct.pack('<H B B f f f f H B', 0xAA55, 2, motor_id, kp, ki, kd, kff, min_pwm, kp_sync_x100)
        crc = calculate_crc8(payload)
        packet = payload + struct.pack('<B', crc)
        
        try:
            self.ser.write(packet)
        except serial.SerialException as e:
            self.get_logger().error(f"Failed to write to serial: {e}")

    def cmd_vel_cb(self, msg):
        linear_x = msg.linear.x
        angular_z = msg.angular.z
        led_mask = 1 # Опционально: настройка маски светодиодов на основе cmd_vel
        
        # Упаковка сообщения движения (msg_id=1)
        # Заголовок (2), msg_id (1), linear_x (4), angular_z (4), led_mask (1), резерв (11)
        payload = struct.pack('<H B f f B 11s', 0xAA55, 1, linear_x, angular_z, led_mask, b'\x00'*11)
        crc = calculate_crc8(payload)
        packet = payload + struct.pack('<B', crc)
        
        try:
            self.ser.write(packet)
        except serial.SerialException as e:
            self.get_logger().error(f"Failed to write cmd_vel to serial: {e}")

    def rx_loop(self):
        while rclpy.ok():
            try:
                sync = self.ser.read(1)
                if sync == b'\xBB':
                    sync2 = self.ser.read(1)
                    if sync2 == b'\xBB':
                        # Чтение 24 байт энкодеров + 1 байт CRC
                        data = self.ser.read(25)
                        if len(data) == 25:
                            packet_except_crc = b'\xBB\xBB' + data[:-1]
                            crc_recv = data[-1]
                            
                            if calculate_crc8(packet_except_crc) == crc_recv:
                                encoders = struct.unpack('<6i', data[:-1])
                                self.update_odometry(encoders)
                            else:
                                self.get_logger().warn("UART RX CRC Error")
            except serial.SerialException as e:
                self.get_logger().error(f"Serial read error: {e}")
                time.sleep(1.0)
            except Exception as e:
                self.get_logger().error(f"Unexpected error in rx_loop: {e}")
                time.sleep(1.0)

    def update_odometry(self, encoders):
        if self.prev_encoders is None:
            self.prev_encoders = encoders
            return

        delta_encoders = [encoders[i] - self.prev_encoders[i] for i in range(6)]
        self.prev_encoders = encoders
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

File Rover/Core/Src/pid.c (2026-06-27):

#include "pid.h"
#include "encoder.h"

// Определение глобальных контроллеров
Master_PID left_board_pid;
Master_PID right_board_pid;
Slave_Controller wheel_slaves[6];

void Master_PID_Init(Master_PID *pid, float kp, float ki, float kd,
                     float kff, float min_pwm_offset, float out_max) {
    pid->kp = kp;
    pid->ki = ki;
    pid->kd = kd;
    pid->kff = kff;
    pid->min_pwm_offset = min_pwm_offset;
    pid->integral_sum = 0.0f;
    pid->prev_error = 0.0f;
    pid->out_max = out_max;
}

void Slave_Init(Slave_Controller *slave, float kp_sync) {
    slave->kp_sync = kp_sync;
}

/**
 * Вычисление базового ШИМ для всего борта (Master)
 */
float calculate_master_pwm(Master_PID *pid, float target_vel, float current_avg_vel, float dt) {
    float error = target_vel - current_avg_vel;
    
    // ПИД
    float P = pid->kp * error;
    pid->integral_sum += error * dt;
    // Anti-windup (ограничение интегратора)
    if (pid->integral_sum > (pid->out_max / 2.0f)) pid->integral_sum = (pid->out_max / 2.0f);
    if (pid->integral_sum < -(pid->out_max / 2.0f)) pid->integral_sum = -(pid->out_max / 2.0f);
    float I = pid->ki * pid->integral_sum;
    float D = pid->kd * ((error - pid->prev_error) / dt);
    pid->prev_error = error;
    
    // Feed-Forward
    float ff_output = 0.0f;
    if (target_vel > 0.001f) {
        ff_output = (pid->kff * target_vel) + pid->min_pwm_offset;
    } else if (target_vel < -0.001f) {
        ff_output = (pid->kff * target_vel) - pid->min_pwm_offset;
    }
    
    return P + I + D + ff_output;
}

/**
 * Главная функция обновления скоростей (Вызывать каждые 20 мс)
 * @param target_left_vel  Целевая скорость левого борта (из кинематики ROS2)
 * @param target_right_vel Целевая скорость правого борта
 * @param dt               Шаг времени (0.02 сек)
 * @param output_pwm       Массив куда запишется итоговый ШИМ для 6 моторов
 */
void update_rover_control(float target_left_vel, float target_right_vel, float dt, float *output_pwm) {
    
    // 1. Считаем среднюю скорость каждого борта (по реальным энкодерам)
    float avg_left_vel = (current_wheel_speeds[0] + current_wheel_speeds[1] + current_wheel_speeds[2]) / 3.0f;
    float avg_right_vel = (current_wheel_speeds[3] + current_wheel_speeds[4] + current_wheel_speeds[5]) / 3.0f;
    
    // 2. Master: Вычисляем базовый ШИМ для каждого борта
    float base_pwm_left = calculate_master_pwm(&left_board_pid, target_left_vel, avg_left_vel, dt);
    float base_pwm_right = calculate_master_pwm(&right_board_pid, target_right_vel, avg_right_vel, dt);
    
    // 3. Slave: Распределяем ШИМ по колесам с учетом их индивидуального отклонения от среднего
    // Левый борт (моторы 0, 1, 2)
    for (int i = 0; i < 3; i++) {
        // Если колесо крутится медленнее среднего - добавляем ему мощности, если быстрее - убавляем
        float sync_error = avg_left_vel - current_wheel_speeds[i]; 
        float sync_correction = wheel_slaves[i].kp_sync * sync_error;
        
        output_pwm[i] = base_pwm_left + sync_correction;
    }
    
    // Правый борт (моторы 3, 4, 5)
    for (int i = 3; i < 6; i++) {
        float sync_error = avg_right_vel - current_wheel_speeds[i]; 
        float sync_correction = wheel_slaves[i].kp_sync * sync_error;
        
        output_pwm[i] = base_pwm_right + sync_correction;
    }
    
    // 4. Ограничение финального ШИМ
    for (int i = 0; i < 6; i++) {
        if (output_pwm[i] > left_board_pid.out_max) output_pwm[i] = left_board_pid.out_max;
        if (output_pwm[i] < -left_board_pid.out_max) output_pwm[i] = -left_board_pid.out_max;
    }
}

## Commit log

2026-06-17 feat: initialize STM32 firmware project with HAL drivers, PID control
    [Body (back).stl, Body (bottom) - 1.stl, Body (bottom) - 2.stl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]
2026-06-17 feat: initialize STM32 project structure with CMSIS drivers, HAL libraries, PID control modules
    [Body (back).stl, Body (bottom) - 1.stl, Body (bottom) - 2.stl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]
2026-06-18 feat: implement communication from STM32 to OPi and integrate it into main application loop
2026-06-18 feat: implement motor control, encoder feedback, and PID regulation loops with UART communication
2026-06-20 feat: implement motor control logic and update project documentation
2026-06-20 Update README with STM32 connection details
    Added a reference link for STM32 Nucleo F429ZI.
2026-06-23 fix: исправлен расчёт ШИМ и ПИД-регулятора
    [main.c]
2026-06-24 feat: add uart_bridge_pkg for serial communication with STM32 hardware
2026-06-24 feat: добавлен отладочный топик /encoders_raw
2026-06-24 feat: add web dashboard node for ROS2 telemetry and PID tuning
2026-06-24 feat: добавлен launch-файл
2026-06-24 docs: информация о зависимостях
2026-06-24 feat: интерфейс адаптирован под мобильные устройства
2026-06-27 test: исключение имеющейся реализации ПИД-регулятора для теста логики motor.c (успешно)
2026-06-27 refactor: убрано магическое число и свёрнуто ветвление
2026-06-27 feat: отображение на графике реальной скорости вместо тиков
2026-06-27 refactor: перенос констант и пересчёта тиков за 20 мс в м/с
2026-06-27 feat: настройка протокола под PID-регулятор
2026-06-27 feat!: Master-Slave PID регулятор
2026-06-27 feat: клонирование репо DS4-teleop с изменением максимально возможной скорости
2026-06-27 feat: резервные байты в msg_id = 2 заполнены новыми коэффицентами
2026-06-27 feat: обнуление интегральной суммы при failsafe
    [main.c]
2026-06-27 feat: поддержка отправки новых коэффицентов PID-регулятора
2026-06-27 fix: исправлено отображение графика
2026-06-27 feat: при срабатывании Failsafe синий светодиод на плате STM32 начинает моргать
    [main.c]
2026-06-27 feat: добавлен скрипт для удобного теста ПИД-регулятора

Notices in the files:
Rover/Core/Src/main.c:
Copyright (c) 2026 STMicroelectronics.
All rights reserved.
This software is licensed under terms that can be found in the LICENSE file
